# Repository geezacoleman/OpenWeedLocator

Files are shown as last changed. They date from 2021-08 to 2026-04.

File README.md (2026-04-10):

<p align="center">

</p>

# OpenWeedLocator (OWL)

**Open-source, low-cost weed detection for site-specific weed control**






OWL is a camera-based weed detection system based on the Raspberry Pi that uses green-detection algorithms to trigger relay-controlled solenoids for spot spraying. It's built entirely from off-the-shelf components and 3D-printable parts, making precision weed control accessible to anyone.

[**Website**](https://www.openweedlocator.org) | [**Documentation**](https://docs.openweedlocator.org) | [**Community**](https://community.openweedlocator.org) | [**Newsletter**](https://openagtech.beehiiv.com/)

### OWLs in Action

<table>
  <tr>
    <th>2m vehicle OWL</th>
    <th>2m robot-mounted OWL</th>
    <th>Bicycle OWL</th>
  </tr>
  <tr>
    <td align="center">
      
    </td>
    <td align="center">
      
    </td>
    <td align="center">
      
    </td>
  </tr>

  <tr>
    <th>12m X-fold OWL (in development)</th>
    <th>4m OWL sprayer</th>
    <th>16 channel vegetables OWL</th>
  </tr>
  <tr>
    <td align="center">
      
    </td>
    <td align="center">
      
    </td>
    <td align="center">
      
    </td>
  </tr>
</table>

---

## Quick Start

```bash
# Clone and install on Raspberry Pi (Bookworm or Trixie OS)
git clone https://github.com/geezacoleman/OpenWeedLocator owl
bash owl/owl_setup.sh
```
During this process you'll be asked to setup:
1. Green-on-Green - this adds about 2GB of dependencies
2. Dashboard - standlone or networked

One complete you'll need to reboot and then it should be running.

To confirm, run `sudo systemctl status owl.service` or `sudo journalctl -u owl.service -f`

See the [two step installation guide](https://docs.openweedlocator.org/en/latest/software/index.html) for detailed instructions.

## Documentation

- [**Getting Started**](https://docs.openweedlocator.org/en/latest/getting-started/index.html) - What you need, how it works
- [**Hardware Assembly**](https://docs.openweedlocator.org/en/latest/hardware/index.html) - Parts list, wiring, 3D printing
- [**Software Setup**](https://docs.openweedlocator.org/en/latest/hardware/index.html) - Installation, configuration, algorithms
- [**Controller Setup**](https://docs.openweedlocator.org/en/latest/controllers/index.html) - Standalone and networked dashboards
- [**Troubleshooting**](https://docs.openweedlocator.org/en/latest/troubleshooting/index.html) - Common issues and fixes

### Contributing

Contributions are welcome! See [CONTRIBUTING.md](CONTRIBUTING.md) for guidelines, or join the conversation at [community.openweedlocator.org](https://community.openweedlocator.org).

## Citing OWL

OpenWeedLocator was originally published in [Scientific Reports](https://www.nature.com/articles/s41598-021-03858-9). 
```
@article{Coleman2022,
author = {Coleman, Guy and Salter, William and Walsh, Michael},
doi = {10.1038/s41598-021-03858-9},
issn = {2045-2322},
journal = {Scientific Reports},
number = {1},
pages = {170},
title = {{OpenWeedLocator (OWL): an open-source, low-cost device for fallow weed detection}},
url = {https://doi.org/10.1038/s41598-021-03858-9},
volume = {12},
year = {2022}
}

```
The OWL speed testing paper has been published in [Computers and Electronics in Agriculture](https://www.sciencedirect.com/science/article/pii/S0168169923008074). Please
consider citing the published article using the details below.
```
@article{Coleman2023,
author = {Coleman, Guy R.Y. and Macintyre, Angus and Walsh, Michael J. and Salter, William T.},
doi = {10.1016/j.compag.2023.108419},
issn = {0168-1699},
journal = {Computers and Electronics in Agriculture},
pages = {108419},
title = {{Investigating image-based fallow weed detection performance on Raphanus sativus and Avena sativa at speeds up to 30 km h$^{-1}$}},
url = {https://doi.org/10.1016/j.compag.2023.108419},
volume = {215},
year = {2023}
}
```

### License

This project is licensed under the [MIT License](LICENSE).

## Star History

Star History Chart (https://star-history.com/#geezacoleman/OpenWeedLocator&Timeline)

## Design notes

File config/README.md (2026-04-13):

# Configuration Files

OWL uses INI configuration files to control both detection behaviour and system infrastructure. These are split into two types: **detection config** and **infrastructure config**.

## Detection Config (GENERAL_CONFIG.ini)

`GENERAL_CONFIG.ini` is the single unified detection configuration file. It controls algorithm choice, colour thresholds, camera settings, relay wiring, data collection, tracking, and sensitivity presets -- all in one file.

`GENERAL_CONFIG.ini` and `CONTROLLER.ini` are **protected defaults** -- the dashboard won't let you overwrite or delete them. When you change settings via the dashboard, OWL creates a timestamped copy (e.g. `config_20260207_153022.ini`) and writes changes there.

### Which config is active?

`active_config.txt` contains the path to the detection config OWL loads on boot. If this file doesn't exist, OWL defaults to `config/GENERAL_CONFIG.ini`. You can change the active config from the dashboard or by editing this file directly.

### Sensitivity presets

Rather than separate config files, sensitivity presets are embedded as sections within `GENERAL_CONFIG.ini`:

| Section | Description |
|---|---|
| `[Sensitivity_Low]` | Fewer false positives, may miss smaller weeds |
| `[Sensitivity_Medium]` | Good general-purpose starting point |
| `[Sensitivity_High]` | Catches more weeds, more likely to spray non-targets |

The `[Sensitivity]` section holds the `active` key (`low`, `medium`, or `high`) which determines which preset is applied. Presets only change the 9 `[GreenOnBrown]` threshold values -- hardware settings (relay count, resolution, GPIO pins) are never touched.

You can create custom presets by saving from the dashboard. Custom presets are saved as additional `[Sensitivity_*]` sections and can be deleted from the dashboard. The three built-in presets (Low/Medium/High) cannot be deleted.

### Key sections in GENERAL_CONFIG.ini

| Section | What it controls |
|---|---|
| `[System]` | Algorithm selection, relay count, actuation timing |
| `[Camera]` | Resolution, exposure compensation, crop factors |
| `[GreenOnBrown]` | Colour thresholds (ExG, Hue, Saturation, Brightness min/max), minimum detection area |
| `[GreenOnGreen]` | YOLO model path, confidence, class filtering, actuation mode (for in-crop weed detection) |
| `[Controller]` | Hardware controller type (`none`, `ute`, `advanced`) and pin mappings |
| `[DataCollection]` | Image sampling settings, save directory, logging |
| `[Relays]` | Maps relay IDs to GPIO pin numbers |
| `[Tracking]` | ByteTrack weed tracking settings |
| `[Visualisation]` | Display settings when running with `--show-display` |
| `[Sensitivity]` | Active sensitivity preset |
| `[Sensitivity_Low/Medium/High]` | Built-in sensitivity preset thresholds |

---

## All configurable options

Defaults shown are from `GENERAL_CONFIG.ini`.

### `[System]`

| Key | Default | Range / Valid values | Description |
|-----|---|---|---|
| `algorithm` | `exhsv` | `exg`, `exgr`, `maxg`, `nexg`, `exhsv`, `hsv`, `gndvi`, `gog`, `gog-hybrid` | Detection algorithm (see table below) |
| `input_file_or_directory` | *(empty)* | File or directory path | Path to video, image, or directory for offline processing. Leave empty for live camera |
| `relay_num` | `4` | 0+ (integer) | Number of relays connected to the OWL. Must match entries in `[Relays]` |
| `actuation_duration` | `0.15` | Seconds (float) | How long each relay stays on when a weed is detected |
| `delay` | `0` | Seconds (float) | Delay between detection and relay actuation. Use for speed/distance compensation |
| `actuation_zone` | `100` | 1--100 (integer) | Percentage of the frame width used for relay lane mapping |

### Detection algorithms

| Algorithm | Name | Formula / Method | Notes |
|---|---|---|---|
| `exg` | Excess Green | 2g - r - b | Simple and fast. Woebbecke et al. 1995 |
| `exgr` | Excess Green minus Excess Red | ExG - (1.4r - g) | Better soil rejection than ExG alone |
| `maxg` | Maximum Green | 24g - 19r - 2b | Jin et al. 2021 |
| `nexg` | Normalised Excess Green | Standardised ExG using channel ratios | Less sensitive to lighting variation |
| `exhsv` | ExG + HSV combined | Normalised ExG masked by HSV thresholds | **Default.** Best balance of accuracy and robustness |
| `hsv` | HSV thresholding | Hue/Saturation/Value range filter | Fast, but sensitive to lighting changes |
| `gndvi` | Green NDVI | (NIR - green) / (NIR + green) | **Requires NIR camera.** Not for standard setups |
| `gog` | Green-on-Green | Ultralytics YOLO object detection | For in-crop weed detection. Requires a trained model (see `[GreenOnGreen]`) |
| `gog-hybrid` | AI + Colour | YOLO crop mask + ExHSV colour detection | Uses YOLO to identify crop regions, then runs ExHSV on non-crop areas. Best of both worlds for in-crop scenarios |

All algorithms except `gog`, `gog-hybrid`, and `hsv` use the `[GreenOnBrown]` thresholds. The `hsv` algorithm uses only the HSV thresholds (hue, saturation, brightness). The `gog` algorithm ignores `[GreenOnBrown]` entirely and uses `[GreenOnGreen]` settings instead. The `gog-hybrid` algorithm uses both `[GreenOnGreen]` (for YOLO crop detection) and `[GreenOnBrown]` (for ExHSV weed detection in non-crop areas).

### `[Camera]`

| Key | Default | Range / Valid values | Description |
|-----|---|---|---|
| `resolution_width` | `1456` | 1+ (integer) | Camera capture width in pixels |
| `resolution_height` | `1088` | 1+ (integer) | Camera capture height in pixels |
| `exp_compensation` | `-2` | -10 to 10 (integer) | Exposure compensation. Negative = darker (reduces sky/soil glare) |
| `crop_factor_horizontal` | `0.02` | 0.0 to 0.5 (float) | Fraction of image width to crop from each side. Removes edge distortion |
| `crop_factor_vertical` | `0.02` | 0.0 to 0.5 (float) | Fraction of image height to crop from top and bottom |

Higher resolution gives better detection of small weeds but is slower. The dashboard provides resolution presets as a dropdown.

### `[GreenOnBrown]`

Used by all algorithms except `gog`. The ExG thresholds are used by `exg`, `exgr`, `maxg`, `nexg`, `exhsv`, and `gndvi`. The HSV thresholds are used by `hsv` and `exhsv`.

| Key | Default | Range | Description |
|-----|---|---|---|
| `exg_min` | `25` | 0--255 | Minimum Excess Green value. Pixels below this are ignored. Higher = stricter |
| `exg_max` | `200` | 0--255 | Maximum Excess Green value. Pixels above this are ignored |
| `hue_min` | `39` | 0--180 | Minimum hue (OpenCV scale). Green vegetation is roughly 35--85 |
| `hue_max` | `83` | 0--180 | Maximum hue |
| `saturation_min` | `50` | 0--255 | Minimum colour saturation. Low values include washed-out/grey pixels |
| `saturation_max` | `220` | 0--255 | Maximum colour saturation |
| `brightness_min` | `60` | 0--255 | Minimum brightness. Low values include very dark pixels (shadows) |
| `brightness_max` | `190` | 0--255 | Maximum brightness. High values include very bright pixels (glare) |
| `min_detection_area` | `10` | 0+ (integer) | Minimum contour area in pixels to count as a weed. Higher = ignore small detections |
| `invert_hue` | `False` | `True` / `False` | If True, detect pixels *outside* the hue range instead of inside. Useful for non-green targets |

**Tuning tips:** Start with the medium sensitivity preset and adjust using `--show-display` or the dashboard sliders. Wider ranges (lower mins, higher maxes) catch more weeds but increase false positives. Narrower ranges are more precise but may miss weeds in variable lighting.

### `[GreenOnGreen]`

Used when `algorithm = gog` or `algorithm = gog-hybrid`. Green-on-Green detection uses [Ultralytics YOLO](https://docs.ultralytics.com/) for object detection or instance segmentation. In `gog` mode, YOLO detects weeds directly. In `gog-hybrid` mode, YOLO identifies crop regions, which are masked out before running ExHSV colour detection on the remaining (non-crop) areas -- this combines AI crop recognition with colour-based weed detection for in-crop scenarios.

**Model format:** NCNN is the recommended format for Raspberry Pi -- it runs fastest on ARM CPUs. PyTorch (.pt) models also work but are slower. To convert a model to NCNN, use `yolo export model=your_model.pt format=ncnn`.

**Model loading:** Point `model_path` at an NCNN directory (containing `.param` and `.bin` files), a `.pt` file, or a parent directory containing models. OWL searches for NCNN models first, then falls back to `.pt` files.

| Key | Default | Range / Valid values | Description |
|-----|---|---|---|
| `model_path` | `models` | Directory or file path | Path to YOLO model. Can be an NCNN directory, `.pt` file, or parent directory containing models |
| `confidence` | `0.5` | 0.0--1.0 (float) | Minimum detection confidence. Lower = more detections (more false positives), higher = fewer but more certain |
| `detect_classes` | *(empty)* | Comma-separated class names | Filter detections to specific classes. Empty = detect all classes the model knows |
| `actuation_mode` | `centre` | `centre`, `zone` | How detections trigger relays (see below) |
| `min_detection_pixels` | `50` | 1+ (integer) | Minimum weed pixels in a relay lane to trigger actuation. Only used in `zone` mode |
| `inference_resolution` | `320` | 160--1280 (integer) | YOLO input resolution for `gog-hybrid` mode. Lower = faster inference, higher = better crop detection. Only used in hybrid mode |
| `crop_buffer_px` | `20` | 0--50 (integer) | Dilation buffer in pixels around detected crop regions in `gog-hybrid` mode. Larger buffer = more area masked as crop (fewer false positives on crop edges). Only used in hybrid mode |

**Actuation modes:**

- **`centre`** (default) -- Uses the centre point of each detection bounding box to determine which relay lane the weed falls in. Works with both detection and segmentation models. Simple and reliable.

- **`zone`** -- Uses the segmentation mask to count weed pixels in each relay lane. A relay fires only if the pixel count exceeds `min_detection_pixels`. **Requires a segmentation model** (detection-only models have no mask data). More precise for large or irregularly shaped weeds.

### `[Tracking]`

Optional weed tracking using ByteTrack. When enabled, YOLO runs in tracking mode to maintain consistent weed IDs across frames. This enables class smoothing (stabilising noisy per-frame class predictions) and crop mask stabilisation (persisting crop masks for a few frames after the crop leaves the field of view).

| Key | Default | Range / Valid values | Description |
|-----|---|---|---|
| `tracking_enabled` | `False` | `True` / `False` | Enable ByteTrack weed tracking |
| `track_class_window` | `5` | 1+ (integer) | Number of recent frames to use for majority-vote class smoothing |
| `track_crop_persist` | `3` | 0+ (integer) | Number of frames to persist a crop mask after the crop is no longer detected. Only used in `gog-hybrid` mode |

### `[Controller]`

Controls the optional hardware input controller (physical switches on the OWL unit). Most users set this to `none` and use the web dashboard instead.

| Key | Default | Range / Valid values | Description |
|-----|---|---|---|
| `controller_type` | `none` | `none`, `ute`, `advanced` | Hardware controller type. `none` = no physical switches |

**Shared LED pins** (used by both Ute and Advanced controllers):

| Key | Default | Range / Valid values | Description |
|-----|---|---|---|
| `status_led_pin` | `40` | 1--40 (BOARD pin) | Status indicator LED (boot, detection, recording states) |
| `gps_led_pin` | `38` | 1--40 (BOARD pin) | GPS status LED (solid = fix, flash = acquiring, double-flash = error) |

**Ute controller** (`controller_type = ute`) -- a single toggle switch:

| Key | Default | Range / Valid values | Description |
|-----|---|---|---|
| `switch_pin` | `36` | 1--40 (BOARD pin) | GPIO pin for the toggle switch |
| `switch_purpose` | `recording` | `recording`, `detection` | What the switch controls. `recording` toggles image saving, `detection` toggles weed detection |

**Advanced controller** (`controller_type = advanced`) -- multiple switches for full field control:

| Key | Default | Range / Valid values | Description |
|-----|---|---|---|
| `detection_mode_pin_up` | `36` | 1--40 (BOARD pin) | Switch pin for detection mode up |
| `detection_mode_pin_down` | `35` | 1--40 (BOARD pin) | Switch pin for detection mode down |
| `recording_pin` | `33` | 1--40 (BOARD pin) | Switch pin to toggle image recording |
| `sensitivity_pin` | `32` | 1--40 (BOARD pin) | Switch pin to cycle sensitivity presets (low/high toggle) |

> **Note:** All pin values use BOARD numbering (physical pin position on the header). Ute and Advanced controllers are mutually exclusive — only pins for the active controller type are used.

The hardware switch cycles between the Low and High sensitivity presets (two-position toggle). The web dashboard supports all three levels (low/medium/high) via MQTT. Both use the `SensitivityManager` which reads from the `[Sensitivity_*]` sections.

### `[Sensitivity]`

| Key | Default | Range / Valid values | Description |
|-----|---|---|---|
| `active` | `medium` | `low`, `medium`, `high`, or custom preset name | The currently active sensitivity preset |

### `[Sensitivity_Low]`, `[Sensitivity_Medium]`, `[Sensitivity_High]`

Each preset section contains the same 9 keys as `[GreenOnBrown]` (the threshold values). When a preset is applied, these values overwrite the corresponding `[GreenOnBrown]` keys at runtime. Example:

```ini
[Sensitivity_Low]
exg_min = 25
exg_max = 200
hue_min = 41
hue_max = 80
saturation_min = 52
saturation_max = 218
brightness_min = 62
brightness_max = 188
min_detection_area = 20
```

### `[Visualisation]`

| Key | Default | Range / Valid values | Description |
|-----|---|---|---|
| `image_loop_time` | `5` | Seconds (integer) | Time each image is displayed when processing a directory of images with `--show-display` |

### `[DataCollection]`

| Key | Default | Range / Valid values | Description |
|-----|---|---|---|
| `image_sample_enable` | `False` | `True` / `False` | Enable automatic image saving for dataset collection |
| `sample_method` | `whole` | `bbox`, `square`, `whole` | How images are saved. `whole` = full frame, `bbox` = cropped to detection bounding box, `square` = square crop around detection |
| `sample_frequency` | `30` | 1+ (integer) | Save an image every N frames. 30 = roughly once per second at 30fps |
| `save_directory` | `/media/owl/SanDisk` | Directory path | Where to save collected images. Typically a USB drive |
| `detection_enable` | `True` | `True` / `False` | Enable weed detection and relay actuation. Set to `False` for data-collection-only mode |
| `log_fps` | `False` | `True` / `False` | Log frames-per-second to the console |
| `camera_name` | `cam1` | Text string | Identifier for this camera in saved data. Useful for multi-camera rigs |

### `[Relays]`

Maps relay IDs to GPIO board pin numbers. The number of entries here must be at least `relay_num` from `[System]`.

| Key | Default | Range | Description |
|-----|---|---|---|
| `0` | `13` | 1--40 (board pin) | GPIO pin for relay 0 (leftmost spray zone) |
| `1` | `15` | 1--40 (board pin) | GPIO pin for relay 1 |
| `2` | `16` | 1--40 (board pin) | GPIO pin for relay 2 |
| `3` | `18` | 1--40 (board pin) | GPIO pin for relay 3 (rightmost spray zone) |

Add more entries (e.g. `4 = 22`) if you have more than 4 relays, and update `relay_num` to match.

---

## Infrastructure Config (CONTROLLER.ini)

`CONTROLLER.ini` controls how OWL connects to dashboards, networks, and GPS. It is **not included in the repository** -- it gets created automatically when you run the setup script (`owl_setup.sh`).

If `CONTROLLER.ini` does not exist, OWL runs in basic detection-only mode with no MQTT, no web dashboard, and no remote control. This is the default for a fresh install.

See `CONTROLLER_TEMPLATE.ini` for a fully documented reference with explanations of every setting. To create one manually:

```bash
cp config/CONTROLLER_TEMPLATE.ini config/CONTROLLER.ini
# Then edit CONTROLLER.ini with your settings
```

### Key sections in CONTROLLER.ini

| Section | What it controls |
|---|---|
| `[MQTT]` | Enable/disable MQTT, broker address, device ID |
| `[Network]` | Operation mode (`standalone` or `networked`), IP addresses |
| `[WebDashboard]` | Flask dashboard port |
| `[GPS]` | GPS source, serial settings, networked GPS server config |
| `[Actuation]` | Speed-adaptive actuation settings |

## How the two files work together

OWL reads both files on startup. `GENERAL_CONFIG.ini` is read first, then `CONTROLLER.ini` is layered on top. If the same key exists in both files, `CONTROLLER.ini` wins (this is how Python's ConfigParser merge works). This means old custom configs that still have `[MQTT]` or `[Network]` sections will still work -- `CONTROLLER.ini` values take precedence.

## Operation Modes

OWL supports three ways of running, depending on your setup:

### No controller (default)

Out of the box, with no setup script run and no `CONTROLLER.ini`, OWL just does detection. No dashboard, no MQTT, no remote control. It reads images from the camera, runs the detection algorithm, and triggers relays. This is the simplest setup -- just wire it up, power it on, and it works.

**When to use:** Single OWL unit where you just need it to spray weeds. No touchscreen, no remote monitoring needed. Configure detection thresholds using `--show-display` on a monitor, save to a preset file, and let it run.

### Standalone mode

A single OWL with its own WiFi hotspot and web dashboard. The OWL creates a WiFi network you can connect to from a phone, tablet, or in-cab touchscreen. The dashboard lets you start/stop detection, adjust thresholds with live camera preview, save presets, and monitor system health -- all from a browser.

Everything runs on one Pi: the detection loop, the MQTT broker, the web server, and the dashboard.

**When to use:** Single OWL unit where you want a touchscreen or remote control. Typical setup: OWL Pi with a 7" touchscreen mounted in the cab, connected to the OWL's own hotspot.

**Setup:** Run `owl_setup.sh`, select "yes" to dashboard, then select "Standalone" mode. The setup script creates the hotspot, installs the MQTT broker, configures Nginx, and writes `CONTROLLER.ini` with `mode = standalone`.

### Networked mode

Multiple OWLs connected to a shared WiFi network, all reporting to a central controller. The central controller runs on a separate Pi (typically in the cab with a touchscreen) and shows all connected OWLs in one dashboard. You can monitor, control, and configure every OWL from a single screen.

Each OWL connects to the network as a client with a static IP and publishes its state to the central MQTT broker. The central controller discovers OWLs automatically -- no manual registration needed.

**When to use:** Multi-boom or multi-unit setups. For example, a 36m spray rig with 3 OWLs each covering 12m, all visible and controllable from one in-cab display.

**Setup requires two scripts:**

1. **On the central controller Pi:** Run `controller/networked/in-cab_controller_setup.sh`. This installs the MQTT broker, the networked dashboard, configures WiFi, and optionally sets up kiosk mode for a touchscreen.

2. **On each OWL Pi:** Run `owl_setup.sh`, select "yes" to dashboard, then select "Networked" mode. Enter the central controller's IP when prompted. The setup script configures WiFi as a client, writes `CONTROLLER.ini` with `mode = networked` and the broker IP pointing to the controller.

## GPS Setup

OWL supports GPS tracking via a Teltonika RUTX14 (or similar) industrial router that pushes NMEA sentences over TCP. GPS data is used for:

- Live speed, heading, and satellite display on the GPS tab
- Session statistics: distance travelled, time active, area covered (hectares)
- GeoJSON track recording saved to disk for each detection session

### How it works

The **central controller** (networked mode) runs a TCP server that listens for NMEA connections. The Teltonika router connects to this server and pushes standard NMEA sentences (`$GPRMC`, `$GPGGA`, `$GPVTG`, `$GPGSV`). The GPS Manager parses these, updates the live GPS state, and feeds the session tracker and track recorder.

```
Teltonika RUTX14          Central Controller (Pi)           Browser
    GPS antenna               GPSManager                    GPS Tab
        |                         |                            |
        +--- NMEA over TCP ------>| port 8500                  |
                                  |  parse NMEA                |
                                  |  update GPSState           |
                                  |  update SessionStats       |
                                  |  write GeoJSON track       |
                                  |                            |
                                  +--- /api/gps (JSON) ------->|
                                                               | speed, heading
                                                               | satellites, area
```

Sessions auto-start when any OWL begins detection and auto-stop when all OWLs stop.

### Step 1: Configure CONTROLLER.ini on the central controller

Edit `config/CONTROLLER.ini` on the Pi running the networked controller:

```ini
[GPS]
# Enable the GPS TCP server
enable = True

# TCP port to listen on (must match Teltonika config)
nmea_port = 8500

# Spray boom width in metres (for area calculation)
boom_width = 12.0

# Directory for GeoJSON track files
track_save_directory = tracks
```

The `source`, `port`, and `baudrate` keys are only used by owl.py for serial GPS modules -- they are ignored by the networked controller.

### Step 2: Configure the Teltonika RUTX14

On the Teltonika router's web interface (typically `192.168.1.1`):

1. **Services > GPS > General**: Enable GPS
2. **Services > GPS > NMEA Forwarding**:
   - Enable NMEA forwarding
   - Protocol: **TCP**
   - Hostname/IP: the central controller's IP address (e.g. `192.168.1.2`)
   - Port: **8500** (must match `nmea_port` in CONTROLLER.ini)
   - NMEA sentences: enable at minimum **GGA** and **RMC**. Also enable **VTG** (speed) and **GSV** (satellites) for full data.

### Step 3: Firewall

The setup script (`controller/shared/setup.sh`) automatically opens port 8500 in UFW:

```bash
sudo ufw allow 8500/tcp
```

If you didn't use the setup script, add this rule manually.

### Step 4: Verify

1. Restart the networked controller: `sudo systemctl restart owl-controller.service` (or run `python controller/networked/networked.py` manually)
2. Check the logs for: `GPS Manager started on port 8500` and `GPS client connected from ...`
3. Open the GPS tab in the browser -- it should show satellite count, speed, and heading once the Teltonika gets a GPS fix

### Troubleshooting

| Symptom | Cause | Fix |
|---|---|-----|
| GPS tab shows "DISCONNECTED" | GPSManager not started | Check `enable = True` in `[GPS]` section of CONTROLLER.ini |
| GPSManager started but no client connects | Teltonika can't reach the controller | Verify network connectivity: `ping <controller-ip>` from Teltonika. Check UFW: `sudo ufw status` should show 8500/tcp ALLOW |
| Client connects but no fix data | Teltonika GPS has no satellite lock | Check the Teltonika GPS status page. Move to a location with sky visibility. First fix can take several minutes |
| Speed shows 0 but position is valid | VTG sentence not enabled on Teltonika | Enable VTG in Teltonika NMEA forwarding settings |
| Track files are empty | Session never started | Detection must be enabled on at least one OWL. Sessions auto-start/stop with detection |

### GPS config reference

| Key | Used by | Default | Description |
|-----|---|---|---|
| `source` | owl.py | `none` | GPS source for individual OWL (`none`/`serial`/`tcp`) |
| `port` | owl.py | `/dev/ttyUSB0` | Serial port (when `source = serial`) |
| `baudrate` | owl.py | `9600` | Serial baud rate (when `source = serial`) |
| `enable` | networked controller | `False` | Start GPS TCP server on the central controller |
| `nmea_port` | networked controller | `8500` | TCP port for NMEA connections |
| `boom_width` | networked controller | `12.0` | Boom width in metres for area calculation |
| `track_save_directory` | networked controller | `tracks` | Directory for GeoJSON track files |

## Custom presets saved from the dashboard

When you save a new preset from the dashboard (standalone or networked), it creates a timestamped INI file in this directory (e.g. `config_20260207_153022.ini`) and saves the preset as a new `[Sensitivity_*]` section. You can set any saved preset as the active boot config from the dashboard.

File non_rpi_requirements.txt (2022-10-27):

## IMPORTANT - for NON Raspberry Pi use. Only use this file if you are setting up an environment on a non Rasperry Pi device. ##

glob2==0.7
imutils==0.5.4
numpy==1.23.4
opencv-python==4.6.0.66
pandas==1.5.1

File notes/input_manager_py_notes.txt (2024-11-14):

################################################################################
Notes on input_manager.py

Summary completed on 14/11/2024
Summary based on commit 95dfb6b
################################################################################

Purpose:
- Manages physical control interfaces for OWL
- Handles GPIO button inputs
- Controls detection and recording states
- Provides platform compatibility checks

Functions:
- is_raspberry_pi
- get_rpi_version

Classes:
- UteController
- AdvancedController

UteController class:
- Single-switch control interface
- Methods:
  - __init__
  - update_state
  - toggle_state
  - weed_detect_indicator
  - image_write_indicator
  - run
  - stop

UteController class --> __init__ method:
- Takes detection_state, sample_state, stop_flag
- Takes owl_instance, status_indicator
- Takes switch_purpose (recording/detection)
- Takes switch_board_pin, bounce_time
- Initializes GPIO button handlers

UteController class --> update_state method:
- Checks switch position
- Updates detection or recording state
- Toggles LED indicators
- Controls weed detection/image sampling

AdvancedController class:
- Multi-switch interface for advanced control
- Methods:
  - __init__
  - update_state
  - update_recording_state
  - update_sensitivity_state
  - update_sensitivity_settings
  - set_detection_mode
  - update_detection_mode_state
  - weed_detect_indicator
  - image_write_indicator
  - run
  - stop
  - _read_config

AdvancedController class --> __init__ method:
- Takes recording/sensitivity/detection states
- Takes owl_instance, status_indicator
- Takes config paths for sensitivity settings
- Takes button pin mappings and bounce time
- Initializes multiple GPIO buttons
- Sets up button event handlers

AdvancedController class --> update_state method:
- Updates all control states:
  * Recording state
  * Sensitivity state
  * Detection mode state

AdvancedController class --> set_detection_mode method:
- Takes mode parameter (0=detect, 1=off, 2=all on)
- Controls relay states
- Updates status indicators

Platform Handling:
- Detects Raspberry Pi platform
- Provides GPIO access on Pi
- Testing mode on non-Pi platforms
- Version detection for Pi models

Dependencies:
- gpiozero: GPIO control (Pi only)
- configparser: Config file reading
- cv2: GUI trackbar updates
- threading: Process control
- logging: Status messages

GPIO Configuration:
- Button setup with bounce time
- Event handler registration
- State management
- LED indicator control

Thread Safety:
- State locking for shared variables
- Safe process termination
- Event-based status updates

Error Handling:
- Platform compatibility checks
- GPIO initialization errors
- Config file reading errors
- Process management safety

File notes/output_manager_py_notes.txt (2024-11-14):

################################################################################
Notes on output_manager.py

Summary completed on 14/11/2024
Summary based on commit 95dfb6b
################################################################################

Purpose:
- Controls hardware outputs for OWL system
- Manages relay board control and status indicators
- Provides test interfaces for non-Pi development

Classes:
- TestRelay
- TestBuzzer
- TestLED
- BaseStatusIndicator
- HeadlessStatusIndicator
- UteStatusIndicator
- AdvancedStatusIndicator
- RelayControl
- RelayController

Entrypoint:
- Has __main__ check for testing status indicators
- Sets testing flag via get_platform_config() if not on Raspberry Pi
- Uses terminal messages instead of GPIO when in test mode

TestRelay class:
- Simulates relay hardware for testing
- Methods:
  - __init__
  - on
  - off

TestRelay class --> __init__ method:
- Takes relay_number and verbose flag
- Stores them as instance attributes

TestRelay class --> on method:
- Prints "[TEST] Relay {number} ON" if verbose enabled

TestRelay class --> off method:
- Prints "[TEST] Relay {number} OFF" if verbose enabled

TestBuzzer class:
- Simulates buzzer hardware for testing
- Methods:
  - beep

TestBuzzer class --> beep method:
- Takes on_time, off_time, n repeats, verbose flag
- Prints "BEEP" n times if verbose enabled

TestLED class:
- Simulates LED hardware for testing
- Methods:
  - __init__
  - blink
  - on
  - off

TestLED class --> __init__ method:
- Takes pin number
- Stores as instance attribute

TestLED class --> blink method:
- Takes on_time, off_time, n repeats, verbose flag
- Prints "BLINK {pin}" n times if verbose enabled

TestLED class --> on/off methods:
- Print "LED {pin} ON/OFF" respectively

BaseStatusIndicator class:
- Base class for all status indicators
- Handles storage monitoring and LED control
- Methods:
  - __init__
  - start_storage_indicator
  - run_update
  - update
  - error
  - stop

BaseStatusIndicator class --> __init__ method:
- Takes save_directory and no_save flag
- Initializes storage monitoring
- Sets up LED control threads
- Configures system LEDs

BaseStatusIndicator class --> update method:
- Monitors storage usage
- Updates LED states based on storage
- Triggers errors if storage full

HeadlessStatusIndicator class:
- Minimal implementation without physical indicators
- Inherits from BaseStatusIndicator
- Only monitors storage capacity
- Methods:
  - __init__
  - _update_storage_indicator

UteStatusIndicator class:
- Two-LED indicator system
- Inherits from BaseStatusIndicator
- Methods:
  - __init__
  - _update_storage_indicator
  - setup_success
  - image_write_indicator
  - error
  - stop

UteStatusIndicator class --> __init__ method:
- Takes save_directory and LED pin numbers
- Initializes record and storage LEDs
- Sets up status monitoring

UteStatusIndicator class --> _update_storage_indicator method:
- Takes percent_full value
- Changes LED blink patterns based on storage level:
  * >90%: Solid storage LED
  * >85%: Fast blink
  * >80%: Medium blink
  * >75%: Slow blink
  * >50%: Very slow blink
  * <50%: Extremely slow blink

RelayControl class:
- Direct hardware interface for relay board
- Methods:
  - __init__
  - relay_on
  - relay_off
  - beep
  - all_on
  - all_off
  - remove
  - clear
  - stop

RelayControl class --> __init__ method:
- Takes relay_dict mapping relays to GPIO pins
- Initializes buzzer on BOARD7
- Creates OutputDevice for each relay
- Sets up test devices if not on Pi

RelayController class:
- Manages relay timing and job queues
- Methods:
  - __init__
  - receive
  - consumer

RelayController class --> __init__ method:
- Takes relay_dict and visualization flags
- Creates job queues for each relay
- Initializes threading conditions
- Starts consumer threads

RelayController class --> receive method:
- Takes relay, timestamp, location, delay, duration
- Queues spray job for specified relay
- Notifies consumer thread

RelayController class --> consumer method:
- Runs in separate thread for each relay
- Processes queued spray jobs
- Manages timing and relay states
- Coordinates with visualization system

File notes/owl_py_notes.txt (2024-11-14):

################################################################################
Notes on owl.py

Summary completed on 10/11/2024
Summary based on commit: 95dfb6b
################################################################################

Purpose:
- Primary control script for OWL system
- Handles real-time weed detection and sprayer control
- Manages configuration, data collection, and hardware interfaces

Entrypoint:
- Validates Python environment and imports
- Parses command line arguments:
  - --show-display: Enable visualization windows
  - --focus: Add blur detection to output
  - --input: Path to input media (image/video/directory)
- Creates Owl instance with parsed arguments
- Starts detection loop via owl.hoot()

Owl class:
Main methods:
- __init__: System initialization
- hoot: Main detection loop
- stop: Graceful shutdown
- save_parameters: Save current settings
- _log_system_info: Record system details

Initialization (__init__):
1. Configuration
   - Validates config file
   - Sets up logging
   - Initializes detection parameters
   - Creates visualization GUI if enabled

2. Hardware Setup
   - Configures camera (resolution/exposure)
   - Maps GPIO pins to relays
   - Sets up controller (None/Ute/Advanced)
   - Initializes USB storage for data collection

3. Detection Setup
   - Configures spray zones and trigger lines
   - Sets initial algorithm parameters
   - Validates hardware capabilities

Main Loop (hoot):
1. Frame Processing:
   - Acquires frame from camera/file
   - Updates detection parameters
   - Runs weed detection algorithm

2. Detection Response:
   - Maps detected weeds to spray zones
   - Triggers appropriate relays
   - Updates visualization

3. Data Collection:
   - Records frames/regions based on config
   - Manages storage limits
   - Logs performance metrics

4. User Interface:
   - Processes keyboard input
   - Updates display windows
   - Handles recording controls

Error Handling:
- Validates Python environment
- Checks hardware compatibility
- Manages GPIO conflicts
- Handles storage issues
- Reports algorithm errors

Dependencies:
Core:
- OpenCV-Python: Image processing
- NumPy: Array operations
- imutils: Image utilities

Custom modules:
- error_manager: Error handling
- input_manager: Hardware control
- config_manager: Configuration
- video_manager: Camera interface
- image_sampler: Data collection
- algorithms: Detection methods

Configuration:
- Uses .ini format
- Validated sections:
  - System: Core parameters
  - Camera: Image acquisition
  - Controller: Hardware interface
  - DataCollection: Storage settings
  - GreenOnBrown: Detection parameters
  - Relays: GPIO mappings

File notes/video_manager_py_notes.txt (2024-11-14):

################################################################################
Notes on video_manager.py

Summary completed on 14/11/2024
Summary based on commit 95dfb6b
################################################################################

Purpose:
- Manages different camera types for video capture
- Supports Picamera (legacy), Picamera2, and standard webcams
- Provides thread-safe video streaming

Classes:
- WebcamStream
- PiCamera2Stream
- PiCameraStream
- VideoStream

WebcamStream class:
- Handles USB/standard webcams via OpenCV
- Methods:
  - __init__
  - start
  - update
  - read
  - stop

WebcamStream class --> __init__ method:
- Takes camera source number
- Initializes VideoCapture stream
- Sets frame dimensions
- Creates thread for frame updates

WebcamStream class --> update method:
- Runs in separate thread
- Continuously reads frames
- Updates frame buffer
- Handles stream closure

PiCamera2Stream class:
- Handles newer Raspberry Pi cameras
- Methods:
  - __init__
  - start
  - update
  - read
  - stop

PiCamera2Stream class --> __init__ method:
- Takes resolution, exposure compensation
- Configures camera parameters
- Sets up thread synchronization
- Detects camera model (imx296/imx477/imx708)

PiCamera2Stream class --> update method:
- Thread-safe frame capture
- Uses condition/lock for synchronization
- Handles camera cleanup

PiCameraStream class:
- Handles legacy Raspberry Pi camera
- Methods:
  - __init__
  - start
  - update
  - read
  - stop

PiCameraStream class --> __init__ method:
- Takes resolution, exposure compensation
- Sets PiCamera parameters
- Initializes frame buffer
- Creates capture stream

PiCameraStream class --> update method:
- Continuous frame capture
- Updates frame buffer
- Handles resource cleanup

VideoStream class:
- Factory class to create appropriate stream
- Methods:
  - __init__
  - start
  - update
  - read
  - stop

VideoStream class --> __init__ method:
- Detects available camera version
- Creates appropriate stream object
- Sets frame dimensions
- Handles initialization errors

Dependencies:
- cv2: OpenCV camera interface
- picamera/picamera2: Raspberry Pi cameras
- threading: Thread management
- logging: Status and error logging

Thread Safety:
- Lock for frame buffer access
- Condition for frame synchronization
- Event for thread control
- Daemon threads for cleanup

Error Handling:
- Camera initialization failures
- Stream read errors
- Resource cleanup on errors
- Camera version compatibility

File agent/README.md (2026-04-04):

# OWL Agent Runtime

Optional AI chat assistant for the OWL dashboard. Allows users to adjust
detection settings, create custom algorithms, manage widgets, and more through
natural language conversation.

## Structure

```
agent/
  __init__.py        # Package re-exports
  engine.py          # Agentic loop: prompt assembly, LLM streaming, tool execution
  llm_provider.py    # HTTP adapter for Anthropic and OpenAI APIs (requires httpx)
  tool_registry.py   # Decorator-based tool system with tier permissions
  widget_manager.py  # Dashboard widget discovery, validation, and rendering
  sessions/          # Chat session history (git-ignored)
  widgets/           # User-installed dashboard widgets (git-ignored)
```

## Dependencies

The agent requires `httpx` for LLM API calls. This is an **optional** dependency
not included in the base `requirements.txt`.

Install manually:
```bash
pip install httpx
```

Or select "Install AI agent support" during in-cab controller setup.

## Usage

Both controllers import the agent with a `try/except` guard. If `httpx` is not
installed, the agent tab is simply disabled -- the rest of the dashboard works
normally.

```python
from agent import AgentEngine, ToolRegistry, WidgetManager
```

## How it works

1. The **ToolRegistry** discovers `@owl_tool` decorated functions and exposes
   them as JSON schemas to the LLM.
2. The **AgentEngine** assembles a system prompt with current OWL state, streams
   the user's message to an LLM provider, executes any tool calls, and loops
   until the model returns a text response.
3. Tools are organised into tiers: `observe` (read-only), `apply` (change
   settings), and `developer` (file editing, git operations).

## Related

- `custom_algorithms/` (repo root) -- user-created detection algorithms. Shared
  with the core detection pipeline (`greenonbrown.py`), so it lives outside this
  package.
- `controller/shared/js/agent.js` -- frontend chat UI
- `controller/shared/css/_agent.css` -- frontend chat styles

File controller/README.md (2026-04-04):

# Web Controllers

OWL has two web-based dashboards for monitoring and controlling detection in the field. Which one you use depends on whether you have a single OWL or multiple OWLs on one rig.

## Do I need a controller?

No. OWL works perfectly fine without any web controller. By default (fresh install, no setup script run), OWL just runs detection -- camera in, relays out. If all you need is a box that detects weeds and triggers solenoids, you don't need any of this.

The web controllers are for when you want to:
- Start/stop detection from a touchscreen or phone
- Adjust detection thresholds with a live camera preview
- Monitor system health (CPU, memory, temperature)
- Save and load detection presets
- See GPS data and track coverage
- Control multiple OWLs from one screen

## The two controllers

### Standalone (`controller/standalone/`)

For a **single OWL unit** with its own WiFi hotspot.

The OWL Pi creates a WiFi network (e.g. "OWL-1") and runs everything locally -- detection, MQTT broker, web server, and dashboard. Connect to the hotspot from any device and open the dashboard in a browser. Typical setup is a 7" touchscreen mounted in the cab.

**What you get:**
- Live video feed with detection overlay
- Start/stop detection and image recording
- Sensitivity presets (low/medium/high)
- Threshold adjustment with sliders
- System health monitoring (CPU, temp, disk, memory)
- Config file management (save, load, delete presets)

**How to set up:**
```bash
# Run the main setup script
bash owl_setup.sh

# When prompted "Do you want to add a web dashboard?" -> yes
# When prompted for mode -> select "Standalone"
```

This installs the MQTT broker, configures the WiFi hotspot, sets up Nginx with SSL, creates the systemd service, and writes `CONTROLLER.ini` with `mode = standalone`.

**Access:** `https://owl-1.local/` or `https://10.42.0.1/` (after connecting to the OWL's hotspot)

### Networked (`controller/networked/`)

For **multiple OWL units** on a shared WiFi network, managed from one central screen.

A separate Pi acts as the central controller -- it runs the MQTT broker and the networked dashboard. Each OWL connects to the same WiFi network and publishes its status over MQTT. The controller discovers OWLs automatically and shows them all in one interface.

**What you get:**
- All connected OWLs visible in one dashboard
- Per-OWL status cards (online/offline, detection state, system health)
- Per-OWL controls (start/stop detection, restart service)
- Live video preview from any selected OWL
- Config editor with range sliders and live preview
- Push configs to individual OWLs or broadcast to all
- Config library (save, load, delete presets on the controller)
- GPS tracking with session stats, distance, area covered

**How to set up -- two steps:**

**Step 1: Set up the central controller Pi**
```bash
# On the controller Pi (the one with the touchscreen in the cab)
sudo bash controller/networked/in-cab_controller_setup.sh
```
This installs the MQTT broker, the networked dashboard, configures WiFi with a static IP, sets up Nginx, and optionally enables kiosk mode for the touchscreen.

**Step 2: Set up each OWL Pi**
```bash
# On each OWL Pi
bash owl_setup.sh

# When prompted "Do you want to add a web dashboard?" -> yes
# When prompted for mode -> select "Networked"
# Enter the central controller's IP when prompted
```
This configures WiFi as a client with a static IP, writes `CONTROLLER.ini` with `mode = networked` and the broker IP pointing to the controller.

**Access:** `https://owl-controller.local/` or `https://<controller-ip>/` (from any device on the same network)

## How MQTT connects everything

All communication between `owl.py` (the detection loop) and the dashboards happens over MQTT -- a lightweight messaging protocol designed for IoT devices.

### Standalone mode

Everything is on one Pi. The MQTT broker, owl.py, and the dashboard all talk over `localhost`. Topics are flat:

```
owl/state       -- OWL publishes its status here (heartbeat every 2s)
owl/commands    -- Dashboard sends control commands here
owl/config      -- Config data responses
```

### Networked mode

The MQTT broker runs on the central controller. Each OWL connects to it remotely and uses device-specific topics so the controller can tell them apart:

```
owl/owl-1/state       -- OWL 1's status
owl/owl-2/state       -- OWL 2's status
owl/owl-1/commands    -- Commands for OWL 1
owl/owl-2/commands    -- Commands for OWL 2
```

The controller subscribes to `owl/+/state` (wildcard) to discover all OWLs automatically. When an OWL stops sending heartbeats for 5 seconds, the controller marks it as offline.

## Directory structure

```
controller/
    standalone/             -- Single-unit dashboard
        standalone.py           Flask app
        templates/              HTML templates
        static/                 CSS and JS (per-controller)

    networked/              -- Multi-unit central controller
        networked.py            Flask app
        in-cab_controller_setup.sh  Setup script for the controller Pi
        templates/              HTML templates
        static/                 CSS and JS (per-controller)

    shared/                 -- Assets used by both controllers
        setup.sh                Setup script for OWL Pi dashboards
        css/                    Shared CSS modules (variables, buttons, etc.)
        js/                     Shared JS modules (API client, utilities, toast)
        images/                 Logos
```

Both controllers import shared CSS and JS from `controller/shared/` for consistent styling and behaviour. Controller-specific assets (layout, tabs, config editor) live in each controller's own `static/` directory.

## Troubleshooting

**Dashboard shows "MQTT Connected" but no OWLs appear (networked mode)**

The OWL is likely publishing to standalone topics (`owl/state`) instead of networked topics (`owl/{device_id}/state`). Check that `CONTROLLER.ini` on the OWL Pi has `mode = networked` under `[Network]`. If it says `standalone`, the OWL's MQTT messages won't match what the networked controller is listening for.

**Can't access the dashboard**

- Check the service is running: `systemctl status owl-dash` (standalone) or `systemctl status owl-controller` (networked)
- Check Nginx: `systemctl status nginx`
- Check MQTT: `systemctl status mosquitto`
- Test MQTT manually: `mosquitto_sub -h localhost -t "owl/#"` (you should see heartbeat messages)

**OWL shows as offline on the controller**

OWLs are marked offline after 5 seconds without a heartbeat. Check:
- Is owl.py running on the OWL? `systemctl status owl.service`
- Can the OWL reach the controller? `ping <controller-ip>` from the OWL
- Is MQTT working? `mosquitto_pub -h <controller-ip> -t "test" -m "hello"` from the OWL

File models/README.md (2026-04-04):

# Green-on-Green Weed Detection with YOLO

The OWL supports AI-based weed detection using Ultralytics YOLO models. This enables in-crop (green-on-green) weed recognition, where colour-based detection alone cannot distinguish weeds from crop.

## Supported Model Formats

| Format | Extension | Speed on Pi | Recommended |
|---|---|---|---|
| NCNN | directory with `.param` + `.bin` | Fastest | Yes |
| PyTorch | `.pt` | Slower | For testing only |

**NCNN is the recommended format for Raspberry Pi deployment.** It provides the fastest CPU inference on ARM processors (~68ms for YOLO11n on Pi 5).

## Model Directory Structure

Place your model files in this `models/` directory:

```
models/
├── yolo11n_ncnn_model/    # NCNN format (recommended for Pi)
│   ├── model.ncnn.param
│   ├── model.ncnn.bin
│   └── metadata.yaml
├── yolo11n.pt             # PyTorch format (slower, for testing)
├── labels.txt             # Legacy file (YOLO uses metadata.yaml instead)
└── README.md              # This file
```

The OWL will auto-detect models in this directory:
1. NCNN subdirectories (highest priority)
2. `.pt` files (fallback)

You can also specify an exact path in config: `model_path = models/my_model_ncnn_model`

## Model Types

YOLO supports two task types, both work with the OWL:

- **Detection models** (`yolo11n.pt`) — output bounding boxes only. Use with `actuation_mode = centre`.
- **Segmentation models** (`yolo11n-seg.pt`) — output bounding boxes + pixel masks. Use with `actuation_mode = centre` or `actuation_mode = zone`.

Both model types also work with `gog-hybrid` mode. Segmentation models provide precise crop boundaries; detection models use filled bounding boxes as crop exclusion zones (coarser but functional). The buffer dilation smooths the edges either way.

The task type is auto-detected from the model's `metadata.yaml`.

## Exporting to NCNN

Export a PyTorch model to NCNN format using the Ultralytics CLI:

```bash
# Install ultralytics with export support
pip install ultralytics[export]

# Export detection model
yolo export model=yolo11n.pt format=ncnn

# Export segmentation model
yolo export model=yolo11n-seg.pt format=ncnn
```

This creates a directory (e.g., `yolo11n_ncnn_model/`) containing the NCNN files. Copy this directory to `models/` on your Pi.

## Training Custom Models

To train a weed detection model on your own data:

1. **Collect and label images** using [Roboflow](https://roboflow.com/) or [Label Studio](https://labelstud.io/)
2. **Train with Ultralytics:**
   ```bash
   yolo detect train data=your_dataset.yaml model=yolo11n.pt epochs=100
   ```
3. **Export to NCNN** (see above)
4. **Deploy:** Copy the NCNN model directory to `models/` on the Pi

For weed detection datasets, see [Weed-AI](https://weed-ai.sydney.edu.au/).

## Configuration

Set these parameters in your config INI file under `[GreenOnGreen]`:

```ini
[GreenOnGreen]
model_path = models                  # Path to model or directory
confidence = 0.5                     # Detection threshold (0.0-1.0)
detect_classes =                     # Comma-separated class names (empty = all)
actuation_mode = centre              # 'centre' or 'zone'
min_detection_pixels = 50            # Min pixels per lane for zone mode
inference_resolution = 320           # YOLO input resolution for hybrid mode (160-1280)
crop_buffer_px = 20                  # Buffer around crop regions in hybrid mode (0-50)
```

Then set `algorithm = gog` (pure AI detection) or `algorithm = gog-hybrid` (AI crop mask + colour weed detection) in the `[System]` section.

## Actuation Modes

- **`centre`** (default) — The centre X coordinate of each detection box determines which relay fires. Works with both detection and segmentation models.
- **`zone`** (segmentation models only) — The frame is divided into lanes (one per relay). If the number of weed pixels in a lane exceeds `min_detection_pixels`, that relay fires. A large weed spanning multiple lanes triggers multiple relays simultaneously.

## Tracking (ByteTrack)

When tracking is enabled (`[Tracking] tracking_enabled = True`), YOLO runs in tracking mode using ByteTrack to maintain consistent weed IDs across frames. This enables:

- **Class smoothing** — noisy per-frame class predictions are stabilised using a majority-vote window (`track_class_window` frames). Reduces flickering between classes.
- **Crop mask stabilisation** — in `gog-hybrid` mode, crop masks persist for `track_crop_persist` frames after the crop leaves the field of view, preventing false spray triggers at crop boundaries.

Tracking config lives in the `[Tracking]` section of `GENERAL_CONFIG.ini`:

```ini
[Tracking]
tracking_enabled = False    # Enable ByteTrack weed tracking
track_class_window = 5      # Frames for majority-vote class smoothing
track_crop_persist = 3      # Frames to persist crop mask (hybrid mode only)
```

## Model Deployment via Dashboard

In networked mode, models can be uploaded to the central controller via the `/models` page and deployed to OWL units over WiFi. NCNN models should be uploaded as `.zip` files (containing `.param` and `.bin` files). The controller stores uploads in `uploads/` and OWLs download deployed models to their local `models/` directory.

## References

- [Ultralytics YOLO Documentation](https://docs.ultralytics.com/)
- [NCNN Export Guide](https://docs.ultralytics.com/integrations/ncnn/)
- [Weed-AI Dataset Repository](https://weed-ai.sydney.edu.au/)

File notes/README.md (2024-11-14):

# OWL Documentation Notes

This directory contains detailed documentation for each component of the OpenWeedLocator (OWL) system.

| File | Description | Last Updated |
|---|---|---|
| [owl.py](owl_py_notes.txt) | Main control script and system initialization | 10/11/2024 |
| [error_manager.py](error_manager_py_notes.txt) | Error handling and management system | 10/11/2024 |
| [video_manager.py](video_manager_py_notes.txt) | Camera handling and video stream management | 10/11/2024 |
| [input_manager.py](input_manager_py_notes.txt) | Physical controls and GPIO management | 10/11/2024 |
| [output_manager.py](output_manager_py_notes.txt) | Relay control and status indicators | 10/11/2024 |

Each note file follows a consistent format:
```
################################################################################
Notes on <filename>

Summary completed on DD/MM/YYYY
Summary based on commit XXXXXXX
################################################################################

Purpose:
- Core functionality overview

Classes:
- List of classes

[Detailed class documentation]
- Methods
- Attributes 
- Dependencies
```

These notes are maintained alongside code changes and are updated with each 
commit that modifies the corresponding file's functionality.

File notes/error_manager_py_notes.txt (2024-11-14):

################################################################################
Notes on error_manager.py

Summary completed on 14/11/2024
Summary based on commit 95dfb6b
################################################################################

Purpose:
- Handles all error management for OWL system
- Provides colored terminal output for errors
- Structures error hierarchy for consistent handling

Class Hierarchy:
- OWLError (Base Exception)
  |- StorageError
     |- USBError
        |- USBMountError
        |- USBWriteError
        |- NoWritableUSBError
     |- StorageSystemError
  |- OWLProcessError
     |- OWLAlreadyRunningError
  |- OWLControllerError
     |- ControllerPinError
     |- ControllerConfigError
  |- OWLConfigError
     |- ConfigFileError
     |- ConfigSectionError
     |- ConfigKeyError
     |- ConfigValueError
  |- AlgorithmError
  |- OpenCVError
  |- DependencyError

OWLError class:
- Base exception for all OWL errors
- Methods:
  - __init__
  - colorize
  - format_error_header
  - format_section

OWLError class --> __init__ method:
- Takes message and details dictionary
- Sets timestamp and error ID
- Initializes base Exception

OWLError class --> colorize method:
- Takes text, color, bold flag, underline flag
- Returns ANSI-colored string for terminal output

StorageError classes:
- USBMountError: USB device mounting failures
- USBWriteError: USB write permission issues
- NoWritableUSBError: No available USB storage
- StorageSystemError: Platform compatibility issues

OWLProcessError classes:
- OWLAlreadyRunningError: Handles duplicate instances
- Methods:
  - get_owl_processes: Lists running OWL instances

OWLControllerError classes:
- ControllerPinError: GPIO pin configuration issues
- ControllerConfigError: Controller setup problems

OWLConfigError classes:
- ConfigFileError: Missing/invalid config file
- ConfigSectionError: Missing required sections
- ConfigKeyError: Missing required keys
- ConfigValueError: Invalid configuration values

AlgorithmError class:
- Handles detection algorithm failures
- Methods:
  - handle: Logs error and stops OWL
- Predefined messages for:
  - ModuleNotFoundError
  - IndexError/FileNotFoundError
  - ValueError

OpenCVError class:
- OpenCV import/initialization failures
- Methods:
  - handle: Logs error and exits

DependencyError class:
- Python package dependency issues
- Methods:
  - _format_pip_package_error
  - _format_local_file_error
  - handle

Error Display Features:
- Colored terminal output
- Standardized error headers
- Formatted error sections
- Timestamped error IDs
- Detailed error messages

Dependencies:
- subprocess: Process management
- logging: Error logging
- pathlib: Path handling
- datetime: Timestamp generation

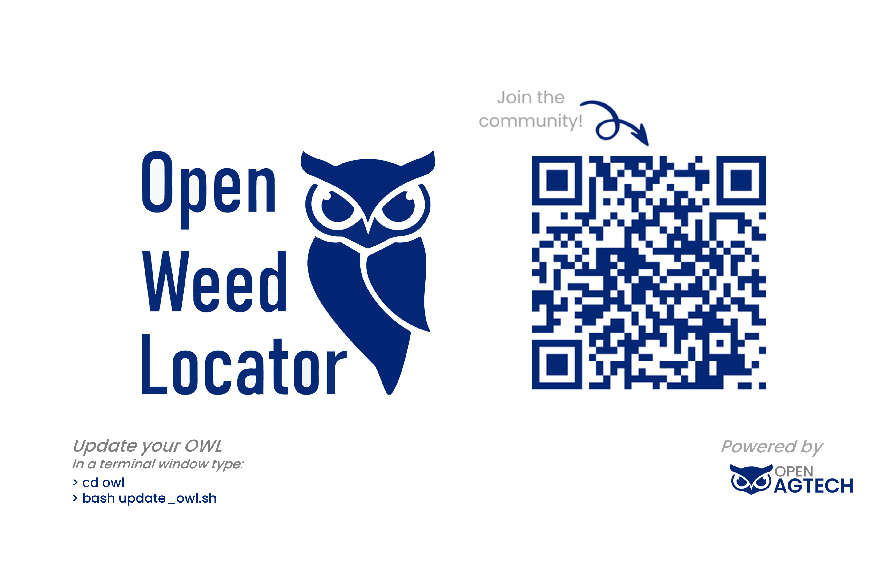
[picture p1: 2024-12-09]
images/owl-background.png

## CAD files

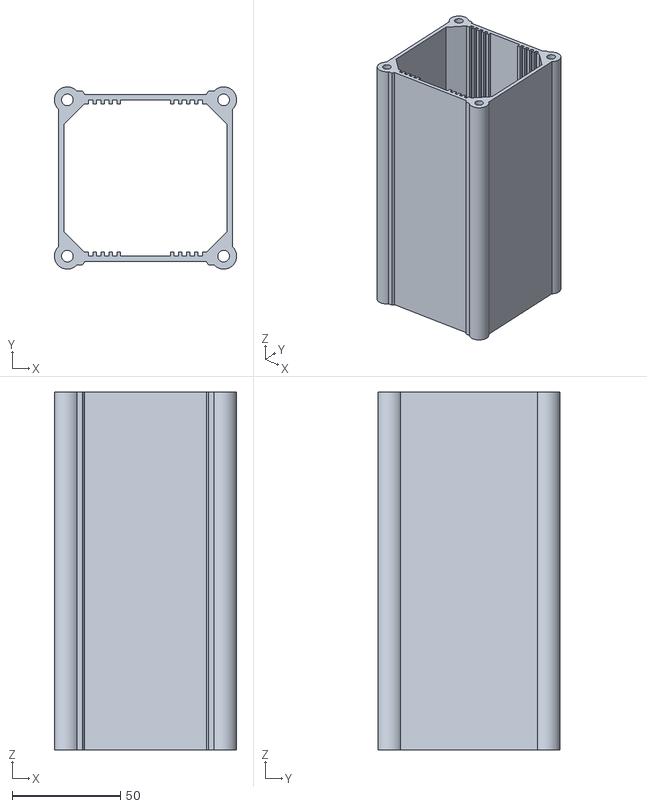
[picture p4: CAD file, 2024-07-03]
3D Models/Compact OWL/Main Body.stl
84.0 x 84.0 x 165.0

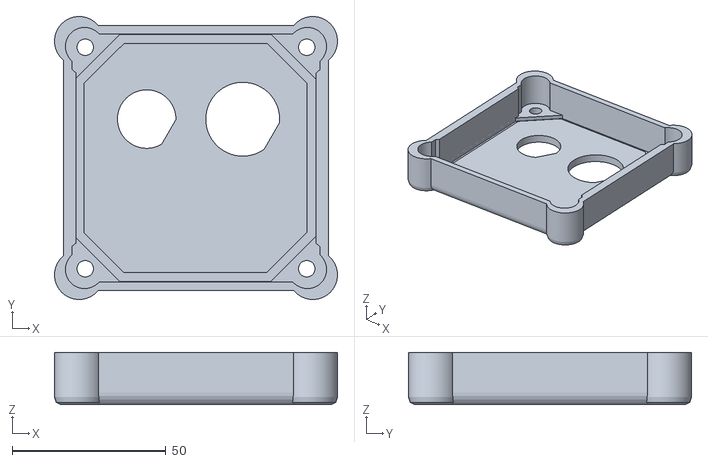
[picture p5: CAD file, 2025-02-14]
3D Models/Compact OWL/Backplate - 2 x Amphenol receptacle.stl
92.0 x 92.0 x 17.0

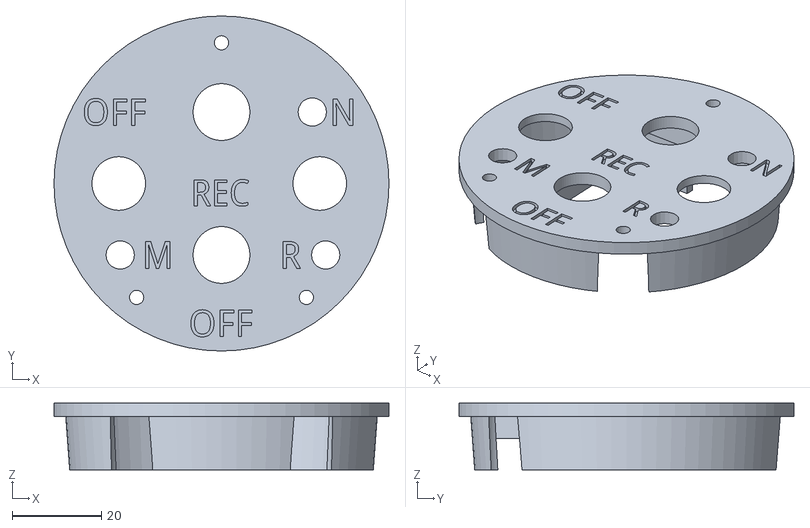
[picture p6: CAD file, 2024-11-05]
3D Models/Controllers/Ute Controller - Top.stl
75.0 x 75.0 x 15.0

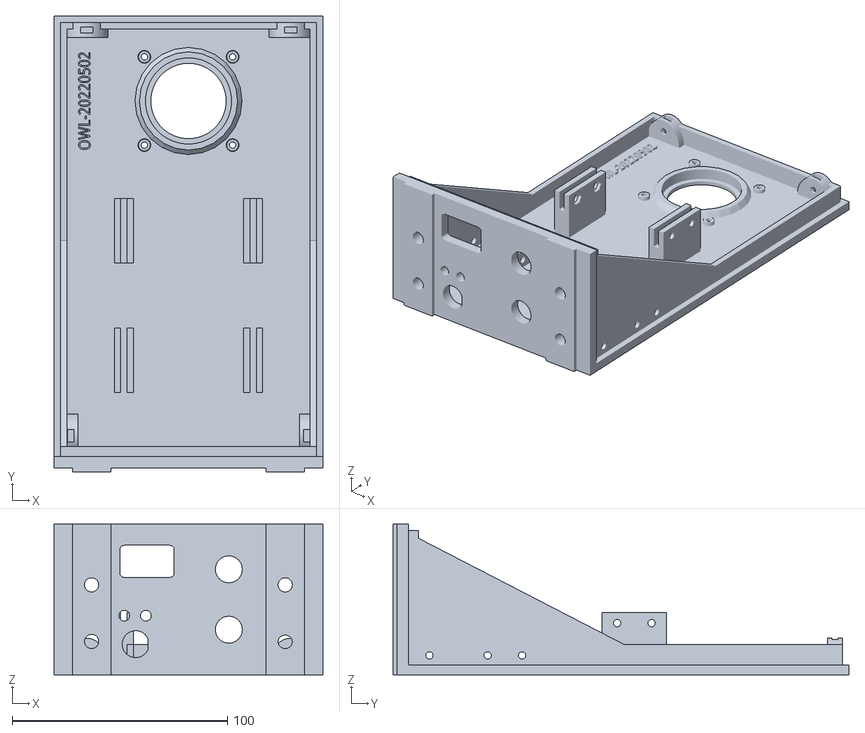
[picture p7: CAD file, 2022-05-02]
3D Models/Original OWL/Enclosure - cable gland.stl
125.0 x 212.0 x 70.0

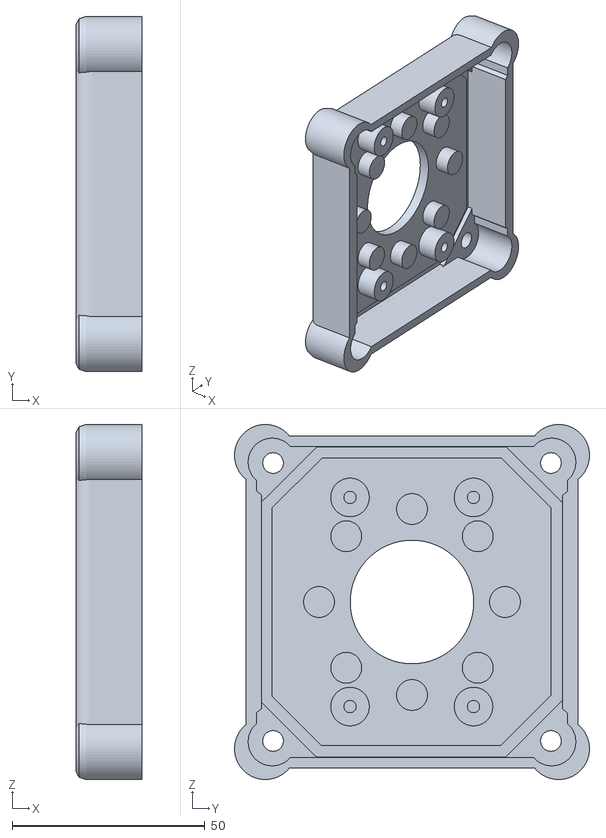
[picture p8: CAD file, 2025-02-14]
3D Models/Compact OWL/Frontplate.stl
17.0 x 92.0 x 92.0

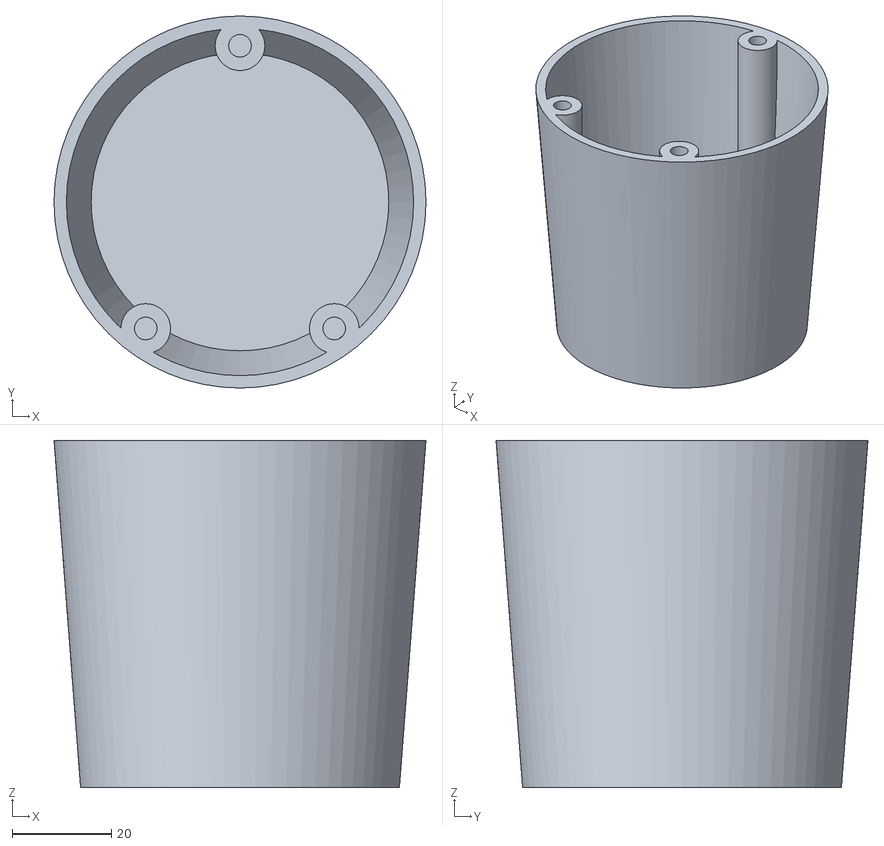
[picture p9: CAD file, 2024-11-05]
3D Models/Controllers/Ute Controller - Base.stl
75.0 x 75.0 x 70.0

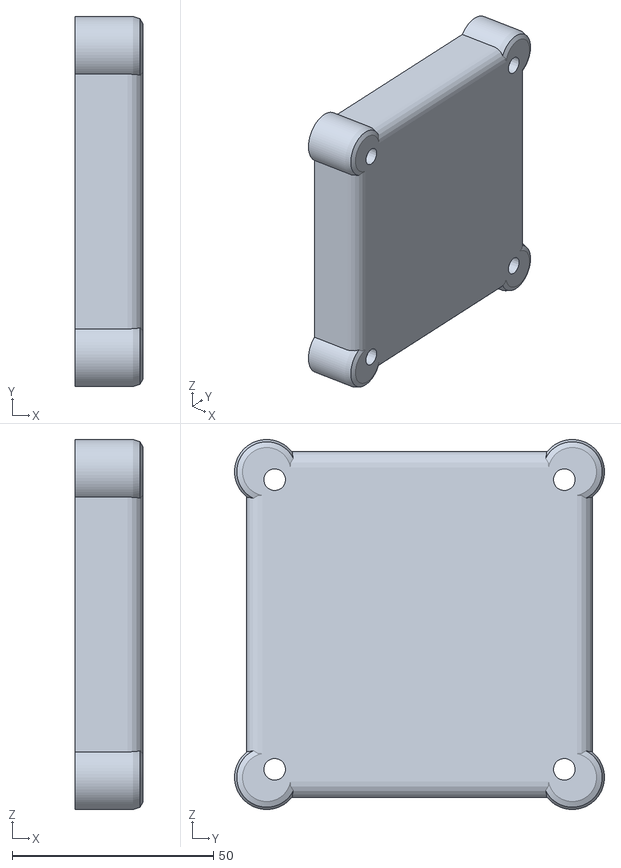
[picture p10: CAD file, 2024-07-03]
3D Models/Compact OWL/Backplate - blank.stl
17.0 x 92.0 x 92.0

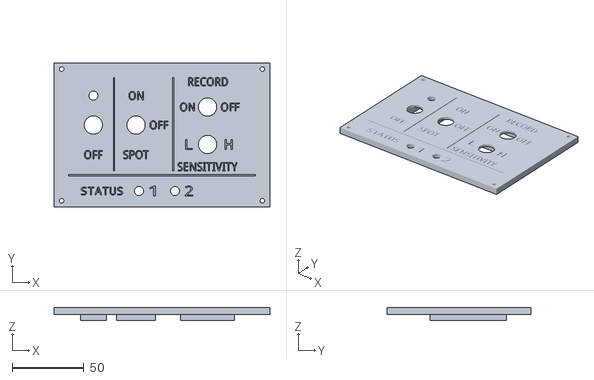
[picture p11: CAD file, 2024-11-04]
3D Models/Controllers/Advanced Controller - Top - Double OWL.stl
150.0 x 99.9 x 9.00

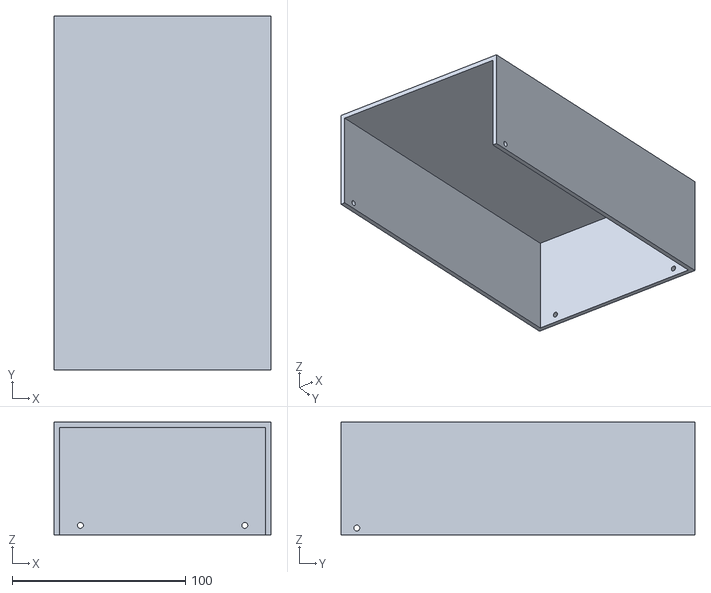
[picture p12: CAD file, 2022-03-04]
3D Models/Original OWL/Enclosure - cover.stl
125.0 x 204.1 x 64.9

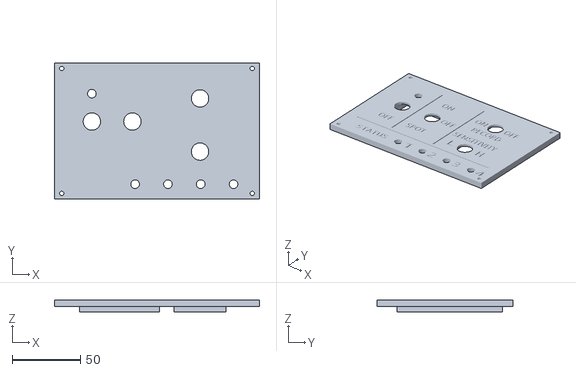
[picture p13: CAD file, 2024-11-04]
3D Models/Controllers/Advanced Controller - Top - 4 OWL.stl
150.0 x 99.9 x 9.00

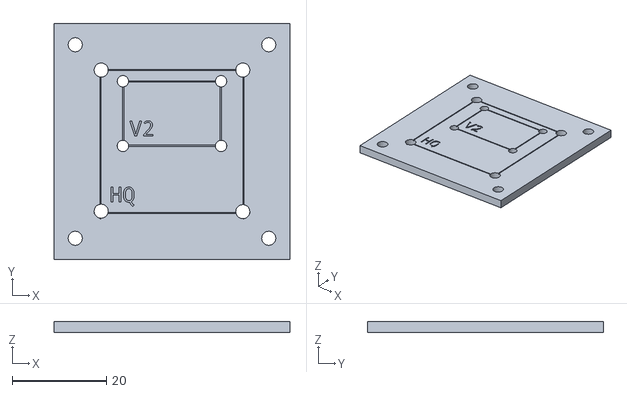
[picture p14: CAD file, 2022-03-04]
3D Models/Original OWL/Camera mount.stl
50.0 x 50.0 x 2.31

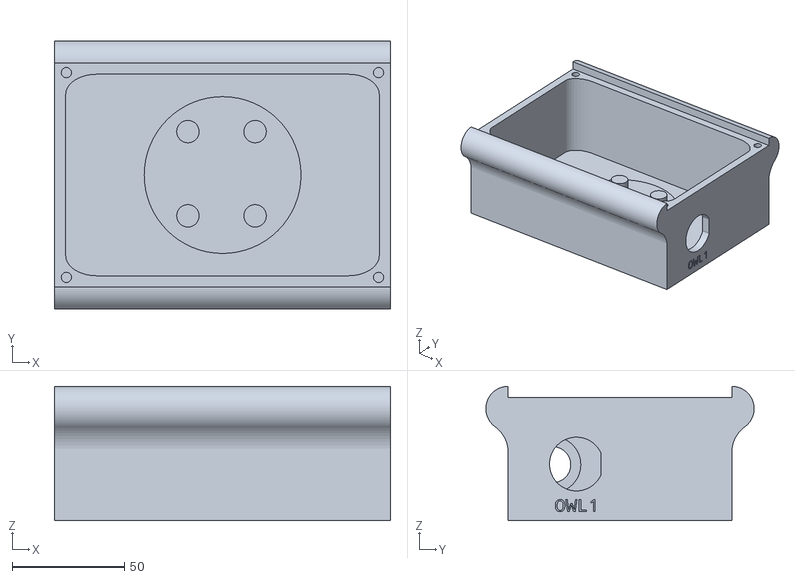
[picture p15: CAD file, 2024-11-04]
3D Models/Controllers/Advanced Controller - Base - Single OWL.stl
150.0 x 119.8 x 60.0

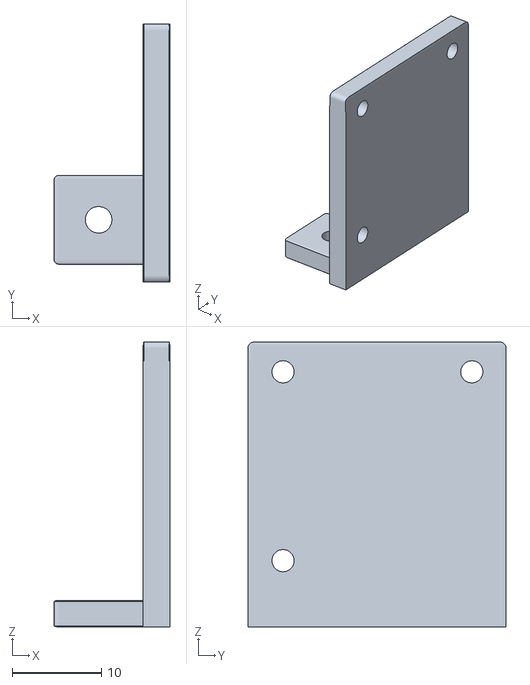
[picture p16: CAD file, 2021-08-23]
3D Models/Original OWL/Voltage regulator mount.stl
13.0 x 29.0 x 32.0

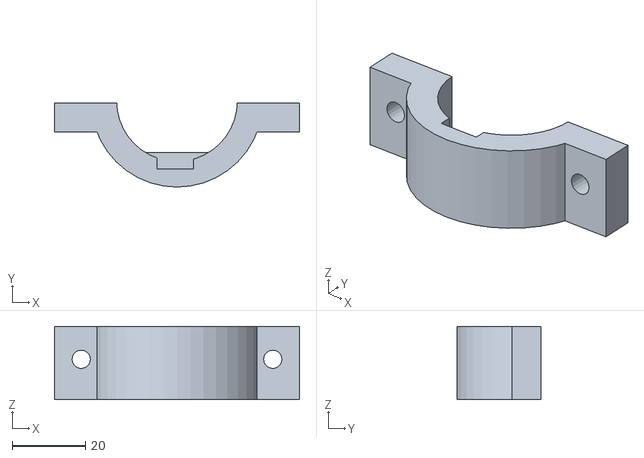
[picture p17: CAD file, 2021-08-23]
3D Models/Original OWL/Solenoid mount - front.stl
67.0 x 23.0 x 20.0

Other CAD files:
3D Models/Original OWL/Enclosure - single connector.stl
3D Models/Compact OWL/Backplate - gland.stl
3D Models/Compact OWL/Backplate - receptacle only.stl
3D Models/Controllers/Advanced Controller - Base - 4 OWL.stl
3D Models/Compact OWL/Backplate - receptacle and ethernet.stl
3D Models/Compact OWL/Camera Mount.stl
3D Models/Compact OWL/Lens Mount.stl
3D Models/Compact OWL/Tray - base.stl
3D Models/Compact OWL/Tray - lens holder.stl
3D Models/Controllers/Advanced Controller - Base - Double OWL.stl
3D Models/Controllers/Advanced Controller - Top - Single OWL.stl
3D Models/Original OWL/Enclosure plug.stl
3D Models/Original OWL/Raspberry Pi mount.stl
3D Models/Original OWL/Relay control board mount.stl
3D Models/Original OWL/Solenoid mount - back.stl
3D Models/Original OWL/Solenoid mount - mid.stl

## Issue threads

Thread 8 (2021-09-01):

STL files as STEP for modification?

rfirth-code, 2021-09-01:
Any chance we could get the .step files for the case and cover that are currently STL downloads?
My 3D printer can't handle the build volume so I was looking to modify for laser cutting instead.
Awesome project!

rfirth-code, 2021-09-01:
@plains203 thanks for the link - do you know if their is any way of downloading this in a 3d format other than STL or OBJ?

plains203, 2021-09-01:
That I don’t know.

geezacoleman, 2021-09-01:
It looks like TinkerCAD doesn't support that conversion, but there are a couple of other ways mentioned [here](https://all3dp.com/2/stl-to-step-how-to-convert-stl-files-to-step/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,to%20upload%20the%20files%20to.&text=From%20there%2C%20you%20can%20select,to%20export%20to%2C%20including%20STEP.), using either Fusion360 or FreeCAD. Hopefully that helps!

If you do end up converting them, open up a pull request and we can add them to the 3D models folder too.

MerbeinRobotics, 2021-09-03:
Hi,  I have the same issue with the size of the cover and case, it's just a bit too big for my Creality Ender 3 3D printer.  But think I can modify the STL file through Fusion 360.  I'll have a go....

But I'm really excited about this project.  I've been working on an autonomous vineyard robot based on the Ardurover/Cube/Mission planner project and the OWL will be perfect for it.    I also wanted to get more familiar with the Raspberry Pi and computer vision and this is the perfect opportunity to do so.

Well done!

Kind Regards,

Stephen

geezacoleman, 2021-09-06:
Thanks Stephen for the feedback! It will be great to see how you use this. Make sure you share the outcome once you're done too and any suggestions for improvements along the way.

Any luck modifying the STL on Fusion 360? @williamtsalter perhaps if you linked the original Tinkercad for the base then it could be ungrouped and more easily adjusted. This length was selected because it only just fit on my Prusa Mk3S.

williamtsalter, 2021-09-06:
@MerbeinRobotics and @geezacoleman, I just had a look at the public model on TinkerCad and you should already be able to ungroup the base for easy modification. It should become a colourful mess when you ungroup. If this isn't the case for you, please let me know as I may have to change the settings for other users.
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

geezacoleman, 2021-09-06:
Thanks @williamtsalter - I just tried that using the link above and the model comes apart nicely as in the image. Ctrl + shift + g to ungroup or there's a button in the top right of the frame.

MerbeinRobotics, 2021-09-07:
Thanks @geezacoleman and @williamtsalter.  After a bit of fiddling with Cura I discovered the case will fit in the Ender 3 if I print it vertically (with the end on the base).  Probably not ideal and I would prefer to print it from the base up.    I have  been able to convert the STL (mesh) file to a solid body in Fusion 360 ready for modification.  My initial thought was to rotate the camera mounts 90 degrees so that I can hopefully shorten the overall length by about 23mm.

geezacoleman, 2021-09-09:
That's good to hear @MerbeinRobotics that it fits - it is quite tall, but hopefully printing it vertically works.

I'll close this issue now as we've addressed the original question, but open up a new issue if you end up shortening it and we can incorporate at short model into the set too.

Closed 2021-09-09.

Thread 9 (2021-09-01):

generate ROS nodes for OWL

geezacoleman, 2021-09-01:
Improve cross compatibility with the fairly widely accepted standard for ag robotics. I'm very unfamiliar with ROS (though really should be better!), so this is a good project if someone wants to take it on.

geezacoleman, 2022-03-22:
Using ROS nodes for the OWL would be a big improvement in functionality, modularity and repeatability, but could throw [some issues with Raspbian vs. Ubuntu](https://roboticsbackend.com/using-ros-on-raspberry-pi-best-practices/).

Will continue looking into it and changing the system over.

EchelonMirror, 2022-09-16:
We can have a chat about this in a couple of months and see how we can help with a ROS2 port (ROS2 is a heck of a lot better).

geezacoleman, 2024-12-16:
That would be great - let me know how it goes and if you have any questions. The main objective would be to allow OWL to be better integrated with field robots instead of just running as a simple python script.

RtJinxuWang, 2025-04-27:
> That would be great - let me know how it goes and if you have any questions. The main objective would be to allow OWL to be better integrated with field robots instead of just running as a simple python script.

Sorry, I was busy with my own precise spraying project some time ago, so I rewrote a system based on ros by myself. I currently only have an nvidia device. When I have time later, I will try to encapsulate OWL into ros on an nvidia device. Besides, I have relatively little knowledge about hardware. I would like to ask you, for example, what types of cameras do the precision spraying company bilberry in France and John Deere's see and spray use? I'm currently using an industrial camera, but it's too severely affected by light!

EchelonMirror, 2025-04-27:
What light issues are you having you having with the industrial camera?

RtJinxuWang, 2025-04-28:
> What light issues are you having you having with the industrial camera?

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
This picture has a particularly poor imaging effect in the shadow state

geezacoleman, 2025-04-30:
> Sorry, I was busy with my own precise spraying project some time ago, so I rewrote a system based on ros by myself. I currently only have an nvidia device. When I have time later, I will try to encapsulate OWL into ros on an nvidia device. Besides, I have relatively little knowledge about hardware. I would like to ask you, for example, what types of cameras do the precision spraying company bilberry in France and John Deere's see and spray use? I'm currently using an industrial camera, but it's too severely affected by light!

That's awesome - would be nice to see OWL on an NVIDIA device with ROS. Let me know how you go.

I'm unsure of the specifics of the hardware those companies use, and they unfortunately don't like to share and I also haven't had the opportunity to pull one apart! For research we have used FLIR Blackfly and LucidVision TritonS machine vision cameras. All struggle with harsh shadows unfortunately, which is why many companies invest in strobe or LED lighting.

The image above though, the information in the shadows is still there, so training a model on the image would likely still work quite well, it would just need data from images with shadows.

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

Closed 2024-11-14.

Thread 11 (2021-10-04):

stronger camera mounts

geezacoleman, 2021-10-04:
Issues with camera mount breaking/weaknesses have become clear. Need a redesign of the mounting hardware to make it sturdier and potentially shorter to fit on smaller print plates.

williamtsalter, 2022-02-28:
I have now printed several updated enclosures that use standoffs to hold the HQ camera in place. These are considerably more robust than the original design. I will have to get some new photos for the hardware assembly instructions in the readme and update the 3d print files. I will do this later this week then close this issue.

williamtsalter, 2022-03-04:
I have now updated the read me and the stl files with the stronger camera mount

Closed 2022-03-04.

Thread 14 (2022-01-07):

Error with file logger

dtms6, 2022-01-07:
Having assembled an OWL and installed the software.I continue to receive the following error once having focused the camera:

FileNotFoundError: [Errno 2] No such file or directory: 'logs/20220108-065504_weed_log.txt'

The error occurs almost instantaneously and kills the program.
There appears to be an issue with inability to write and then recall a file log in the logger directory.

I haven't altered any code and have reinstalled/updated the OWL software just in case, but the error remains.

Would appreciate some guidance.

The output is as follows:

(owl) pi@owl:~ $ ~/owl/./greenonbrown.py
linux
[INFO] Setting up nozzles...
Solenoid 0 OFF
Solenoid 1 OFF
Solenoid 2 OFF
Solenoid 3 OFF
[INFO] Setup complete. Starting spraying.
Solenoid 3 ON
Traceback (most recent call last):
  File "/home/pi/owl/./greenonbrown.py", line 291, in hoot
    self.controller.receive(nozzle=i, delay=delay, timeStamp=sprayTime, duration=sprayDur)
  File "/home/pi/owl/relay_control.py", line 132, in receive
    self.logger.log_line(line)
  File "/home/pi/owl/logger.py", line 17, in log_line
    with open(self.saveDir, 'a+') as file:
FileNotFoundError: [Errno 2] No such file or directory: 'logs/20220108-065030_weed_log.txt'

During handling of the above exception, another exception occurred:

Traceback (most recent call last):
  File "/home/pi/owl/./greenonbrown.py", line 417, in <module>
    minArea=10)
  File "/home/pi/owl/./greenonbrown.py", line 325, in hoot
    self.logger.log_line("[CRITICAL ERROR] STOPPED: {}".format(e))
  File "/home/pi/owl/logger.py", line 17, in log_line
    with open(self.saveDir, 'a+') as file:
FileNotFoundError: [Errno 2] No such file or directory: 'logs/20220108-065030_weed_log.txt'

geezacoleman, 2022-01-07:
Thanks for putting one together and for the heads up!

It looks like this might be an issue with the absolute vs. relative path references where it's looking for `logs/20220108-065030_weed_log.txt` from `(owl) pi@owl:~ $ ~/owl/./greenonbrown.py` where it's looking for that log file in the root directory.

If you try running it from the owl directory, does it work?
`> cd owl`
`> ./greenonbrown.py`

I'll make a quick change to the code to fix it if so.

geezacoleman, 2022-01-07:
Thanks for putting one together and for the heads up!

It looks like this might be an issue with the absolute vs. relative path references where it's looking for `logs/20220108-065030_weed_log.txt` from `(owl) pi@owl:~ $ ~/owl/./greenonbrown.py` where it's looking for that log file in the root directory.

If you try running it from the owl directory, does it work?
`> cd owl`
`> ./greenonbrown.py`

I'll make a quick change to the code to fix it if so.

geezacoleman, 2022-01-07:
Thanks for putting one together and for the heads up!

It looks like this might be an issue with the absolute vs. relative path references where it's looking for `logs/20220108-065030_weed_log.txt` from `(owl) pi@owl:~ $ ~/owl/./greenonbrown.py` where it's looking for that log file in the root directory.

If you try running it from the owl directory, does it work?
`> cd owl`
`> ./greenonbrown.py`

I'll make a quick change to the code to fix it if so.

dtms6, 2022-01-08:
Yes. That resolves the issue! Works a treat.
I'll share some photos of the unit.

geezacoleman, 2022-01-08:
Glad that worked out! I'll leave this issue open for the moment so I can fix it up next week.

Looking forward to see how the unit ended up.

geezacoleman, 2022-01-10:
@dtms6 this should now be fixed - you'll just need to update the owl folder with the latest version of the repo.

dtms6, 2022-01-10:
Yes it fixed the problem. Updated the files and works like a treat. Thanks.

Closed 2022-01-10.

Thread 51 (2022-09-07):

Software issues focusing camera

manninb, 2022-09-07:
Hi,
I'm not able to get an image from the camera up after following the instructions, wondering if anyone can offer help. see below.

pi@raspberrypi:~ $ ps-C greenonbrown.py
bash: ps-C: command not found
pi@raspberrypi:~ $ ps -C greenonbrown.py
  PID TTY          TIME CMD
  533 ?        01:03:14 greenonbrown.py
pi@raspberrypi:~ $ sudo kill 533
pi@raspberrypi:~ $ ~/owl/./greenonbrown.py --show-display
linux
/home/pi/.virtualenvs/owl/lib/python3.7/site-packages/gpiozero/devices.py:290: PinFactoryFallback: Falling back from rpigpio: No module named 'RPi'
  'Falling back from %s: %s' % (name, str(e))))
/home/pi/.virtualenvs/owl/lib/python3.7/site-packages/gpiozero/devices.py:290: PinFactoryFallback: Falling back from lgpio: No module named 'lgpio'
  'Falling back from %s: %s' % (name, str(e))))
/home/pi/.virtualenvs/owl/lib/python3.7/site-packages/gpiozero/devices.py:290: PinFactoryFallback: Falling back from rpio: No module named 'RPIO'
  'Falling back from %s: %s' % (name, str(e))))
/home/pi/.virtualenvs/owl/lib/python3.7/site-packages/gpiozero/devices.py:290: PinFactoryFallback: Falling back from pigpio: No module named 'pigpio'
  'Falling back from %s: %s' % (name, str(e))))
/home/pi/.virtualenvs/owl/lib/python3.7/site-packages/gpiozero/devices.py:285: NativePinFactoryFallback: Falling back to the experimental pin factory NativeFactory because no other pin factory could be loaded. For best results, install RPi.GPIO or pigpio. See https://gpiozero.readthedocs.io/en/stable/api_pins.html for more information.
  warnings.warn(NativePinFactoryFallback(native_fallback_message))
[INFO] Setting up nozzles...
Solenoid 0 OFF
Solenoid 1 OFF
Solenoid 2 OFF
Solenoid 3 OFF
[INFO] Setup complete. Starting spraying.

geezacoleman, 2022-09-07:
Thanks @manninb, based on this [thread](https://forums.raspberrypi.com/viewtopic.php?t=275387), it looks like it could be a Python2 vs Python3 issue for RPi.GPIO

```
sudo apt update
sudo apt install python3-rpi.gpio
```

Let us know how that goes - we will need to update the instructions/requirements.txt file if so!

manninb, 2022-09-07:
It didn't seem to work I put the script in the terminal window an it seemed to run. see below

I closed the unit down and restarted it but could still not get the camera vision.

do you have any other ideas or suggestions as to where I went wrong

pi@raspberrypi:~ $ sudo apt update
Get:1 http://raspbian.raspberrypi.org/raspbian buster InRelease [15.0 kB]
Get:2 http://archive.raspberrypi.org/debian buster InRelease [32.6 kB]
Get:3 http://raspbian.raspberrypi.org/raspbian buster/main armhf Packages [13.0 MB]
Get:4 http://archive.raspberrypi.org/debian buster/main armhf Packages [392 kB]
Get:5 http://raspbian.raspberrypi.org/raspbian buster/contrib armhf Packages [58.8 kB]
Get:6 http://raspbian.raspberrypi.org/raspbian buster/non-free armhf Packages [104 kB]
Fetched 13.6 MB in 47s (287 kB/s)                                      
Reading package lists... Done
Building dependency tree
Reading state information... Done
196 packages can be upgraded. Run 'apt list --upgradable' to see them.
N: Repository 'http://raspbian.raspberrypi.org/raspbian buster InRelease' changed its 'Suite' value from 'stable' to 'oldstable'
N: Repository 'http://archive.raspberrypi.org/debian buster InRelease' changed its 'Suite' value from 'testing' to 'oldstable'
pi@raspberrypi:~ $ sudo apt install python3-rpi.gpio
Reading package lists... Done
Building dependency tree
Reading state information... Done
python3-rpi.gpio is already the newest version (0.7.0-0.1~bpo10+4).
The following package was automatically installed and is no longer required:
  python-colorzero
Use 'sudo apt autoremove' to remove it.
0 upgraded, 0 newly installed, 0 to remove and 196 not upgraded.
pi@raspberrypi:~ $

manninb, 2022-09-07:
Further to the above this is the script I get when I attempt get the camera view

pi@raspberrypi:~ $ ps -c greenonbrown.py
error: unknown user-defined format specifier "nbrown.py"

Usage:
 ps [options]

 Try 'ps --help <simple|list|output|threads|misc|all>'
  or 'ps --help <s|l|o|t|m|a>'
 for additional help text.

For more details see ps(1).
pi@raspberrypi:~ $ ps -C greenonbrown.py
  PID TTY          TIME CMD
  526 ?        01:09:19 greenonbrown.py
pi@raspberrypi:~ $ sudo kill 526
pi@raspberrypi:~ $  ~/owl/./greenonbrown.py --show-display
linux
/home/pi/.virtualenvs/owl/lib/python3.7/site-packages/gpiozero/devices.py:290: PinFactoryFallback: Falling back from rpigpio: No module named 'RPi'
  'Falling back from %s: %s' % (name, str(e))))
/home/pi/.virtualenvs/owl/lib/python3.7/site-packages/gpiozero/devices.py:290: PinFactoryFallback: Falling back from lgpio: No module named 'lgpio'
  'Falling back from %s: %s' % (name, str(e))))
/home/pi/.virtualenvs/owl/lib/python3.7/site-packages/gpiozero/devices.py:290: PinFactoryFallback: Falling back from rpio: No module named 'RPIO'
  'Falling back from %s: %s' % (name, str(e))))
/home/pi/.virtualenvs/owl/lib/python3.7/site-packages/gpiozero/devices.py:290: PinFactoryFallback: Falling back from pigpio: No module named 'pigpio'
  'Falling back from %s: %s' % (name, str(e))))
/home/pi/.virtualenvs/owl/lib/python3.7/site-packages/gpiozero/devices.py:285: NativePinFactoryFallback: Falling back to the experimental pin factory NativeFactory because no other pin factory could be loaded. For best results, install RPi.GPIO or pigpio.
  warnings.warn(NativePinFactoryFallback(native_fallback_message))
[INFO] Setting up nozzles...
Solenoid 0 OFF
Solenoid 1 OFF
Solenoid 2 OFF
Solenoid 3 OFF
[INFO] Setup complete. Starting spraying.
Solenoid 0 ON
Traceback (most recent call last):
  File "/home/pi/owl/./greenonbrown.py", line 285, in hoot
    self.controller.receive(nozzle=i, timeStamp=sprayTime, duration=sprayDur)
  File "/home/pi/owl/relay_control.py", line 132, in receive
    self.logger.log_line(line)
  File "/home/pi/owl/logger.py", line 17, in log_line
    with open(self.saveDir, 'a+') as file:
FileNotFoundError: [Errno 2] No such file or directory: 'logs/20220907-160300_weed_log.txt'

During handling of the above exception, another exception occurred:

Traceback (most recent call last):
  File "/home/pi/owl/./greenonbrown.py", line 406, in <module>
    minArea=10)
  File "/home/pi/owl/./greenonbrown.py", line 319, in hoot
    self.logger.log_line("[CRITICAL ERROR] STOPPED: {}".format(e))
  File "/home/pi/owl/logger.py", line 17, in log_line
    with open(self.saveDir, 'a+') as file:
FileNotFoundError: [Errno 2] No such file or directory: 'logs/20220907-160300_weed_log.txt'
pi@raspberrypi:~ $ ^C

geezacoleman, 2022-09-07:
Thanks for trying that - I think I've worked out why the `PinFactoryFallback: Falling back from rpigpio: No module named 'RPi'` error is occurring. While it is just a warning from gpiozero, the greenonbrown.py script will only start a PiCamera instance if it can find RPi.GPIO, otherwise it defaults to a USB webcam, which is why the camera isn't starting.

This error PinFactoryFallback warning occurs when RPi.GPIO isn't installed - in this case it looks like it isn't installed in the `owl` virtual environment. Assuming you've already made an `owl` environment (looks like that's the case), you'll need to type the following commands:
```
workon owl
pip3 install rpi.gpio

```
This is based on a comment in the [gpiozero docs](https://gpiozero.readthedocs.io/en/stable/faq.html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) FAQs about this warning.

You can also do:
```
workon owl
pip install -r requirements.txt
```
This error should have been fixed previously - make sure you're using the most up to date version of owl, by re-cloning the repository. If that doesn't work, to overcome the `FileNotFoundError` you'll need to launch `greenonbrown.py` from the `owl` directory.

So if you:
```
cd owl
~/owl/./greenonbrown.py --show-display
```

geezacoleman, 2022-09-08:
Has this fixed the camera/logging issues? If so I'll close this issue.

Wifi is probably better addressed by the wider Raspberry Pi community, there could be a few different reasons for that.

manninb, 2022-09-12:
thank, I have got wi fi working for the time being ran the the last lot of script.

pi@raspberrypi:~ $ workon owl
(owl) pi@raspberrypi:~ $ pip3 install rpi.gpio
Looking in indexes: https://pypi.org/simple, https://www.piwheels.org/simple
Collecting rpi.gpio
  Downloading https://www.piwheels.org/simple/rpi-gpio/RPi.GPIO-0.7.1-cp37-cp37m-linux_armv7l.whl (47 kB)

Installing collected packages: rpi.gpio
Successfully installed rpi.gpio-0.7.1
WARNING: You are using pip version 21.1.2; however, version 22.2.2 is available.
You should consider upgrading via the '/home/pi/.virtualenvs/owl/bin/python -m pip install --upgrade pip' command.
(owl) pi@raspberrypi:~ $ workon owl
(owl) pi@raspberrypi:~ $ pip install -r requirements.txt
ERROR: Could not open requirements file: [Errno 2] No such file or directory: 'requirements.txt'
WARNING: You are using pip version 21.1.2; however, version 22.2.2 is available.
You should consider upgrading via the '/home/pi/.virtualenvs/owl/bin/python -m pip install --upgrade pip' command.
(owl) pi@raspberrypi:~ $
(owl) pi@raspberrypi:~ $ cd owl
(owl) pi@raspberrypi:~/owl $ ~/owl/.greenonbrown.py --show-display
bash: /home/pi/owl/.greenonbrown.py: No such file or directory
(owl) pi@raspberrypi:~/owl $

Attempted the camera view procedure again (twice) but was unable to get a view of the camera.

got these results
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
manninb, 2022-09-16:
ps can you tell me the function of the commands below?

cd owl
pip install -r requirements.txt

geezacoleman, 2022-09-16:
The version downloaded from the site is the one that needs updating as mentioned above. It was the original software we had when the OWL was first launched but it is old and has lots of flaws. It works if you run greenonbrown.py from the OWL directory but doesn't if you run it from anywhere else. So I wouldn't redownload/reimage any cards again, just use this one. The version from the download is about a year behind the one you get from updating it.

To get this working you need to :
1. get the latest software from GitHub and save it to a new owl folder on the card, this is what I mean by 'updating'. This is done by following the [Update OWL procedure](https://github.com/geezacoleman/OpenWeedLocator#updating-owl).
2. This procedure guides you through installing all the required libraries/supporting software to avoid the rpi.gpio issue above.
3. Once you have carefully followed this you should have everything working fine.

`pip install -r requirements.txt` installs all the listed packages within the requirements.txt file. It's a faster way of adding all the various packages needed.

`cd` means change directory. It moves into the folder you specify. E.g. `cd owl` moves you into the owl folder if it exists.

geezacoleman, 2022-10-05:
Were you able to fix this @manninb? I might close this if so.

manninb, 2022-10-05:
Thanks, I have been called away to other jobs, but will be back onto this, so far no luck.

manninb, 2022-10-07:
thanks, I have got this to work, This is probably a dumb question but  can you give me the command to go from
(owl) pi@raspberrypi:~/owl $
back to
(owl) pi@raspberrypi:~ $

geezacoleman, 2022-10-07:
Ok great! What did you have to do differently?

Sure thing, just type:
`(owl) pi@raspberrypi: $ cd ..` (should have a space between the `cd` and the two `.`)

manninb, 2022-10-07:
I'm not sure exactly, I may not have been going back to the raspberry from the owl directory if that makes sense. I will try a few other units and see how it goes. There was quite a bit of interest in the OWL at the Nowley field day.

geezacoleman, 2022-10-07:
That's good to hear thanks for talking about it - feel free to write up a summary in the discussions page for any feedback/lessons learned etc.

I'll close this issue now as it's been resolved.

Closed 2022-10-07.

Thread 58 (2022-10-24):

focusing issue

manninb, 2022-10-24:
Had an issue focusing after many successful attempts. I updated software  first but then had trouble getting the PID number, see below.

 pi@raspberrypi:~ $ cd ~
pi@raspberrypi:~ $ mv owl owl-old
pi@raspberrypi:~ $ git clone https://github.com/geezacoleman/OpenWeedLocator
Cloning into 'OpenWeedLocator'...
remote: Enumerating objects: 366, done.
remote: Counting objects: 100% (247/247), done.
remote: Compressing objects: 100% (131/131), done.
remote: Total 366 (delta 163), reused 160 (delta 114), pack-reused 119
Receiving objects: 100% (366/366), 2.87 MiB | 5.26 MiB/s, done.
Resolving deltas: 100% (187/187), done.
pi@raspberrypi:~ $ mv OpenWeedLocator owl
pi@raspberrypi:~ $ cd ~/owl
pi@raspberrypi:~/owl $ pip install -r requirements.txt
Defaulting to user installation because normal site-packages is not writeable
Looking in indexes: https://pypi.org/simple, https://www.piwheels.org/simple
Requirement already satisfied: numpy in /home/pi/.local/lib/python3.7/site-packages (from -r requirements.txt (line 3)) (1.21.6)
Requirement already satisfied: imutils in /home/pi/.local/lib/python3.7/site-packages (from -r requirements.txt (line 4)) (0.5.4)
Requirement already satisfied: gpiozero in /usr/lib/python3/dist-packages (from -r requirements.txt (line 5)) (1.6.2)
Requirement already satisfied: pandas in /home/pi/.local/lib/python3.7/site-packages (from -r requirements.txt (line 6)) (1.3.5)
Requirement already satisfied: glob2 in /home/pi/.local/lib/python3.7/site-packages (from -r requirements.txt (line 7)) (0.7)
Requirement already satisfied: RPi.GPIO in /usr/lib/python3/dist-packages (from -r requirements.txt (line 8)) (0.7.0)
Requirement already satisfied: picamera in /usr/lib/python3/dist-packages (from -r requirements.txt (line 9)) (1.13)
Requirement already satisfied: pytz>=2017.3 in /home/pi/.local/lib/python3.7/site-packages (from pandas->-r requirements.txt (line 6)) (2022.5)
Requirement already satisfied: python-dateutil>=2.7.3 in /home/pi/.local/lib/python3.7/site-packages (from pandas->-r requirements.txt (line 6)) (2.8.2)
Requirement already satisfied: six>=1.5 in /usr/lib/python3/dist-packages (from python-dateutil>=2.7.3->pandas->-r requirements.txt (line 6)) (1.12.0)
WARNING: You are using pip version 21.1.2; however, version 22.3 is available.
You should consider upgrading via the '/usr/bin/python3 -m pip install --upgrade pip' command.
pi@raspberrypi:~/owl $ chmod a+x greenonbrown.py
pi@raspberrypi:~/owl $ chmod a+x owl_boot.sh
pi@raspberrypi:~/owl $ cd ..
pi@raspberrypi:~ $ ps -C greenonbrown.py
  PID TTY          TIME CMD
pi@raspberrypi:~ $

geezacoleman, 2022-10-24:
The `ps -C greenonbrown.py` command will just list anything that is running with 'greenonbrown.py' in the name, so here it looks like `greenonbrown.py` isn't running so you can continue with the focusing by running `./greenonbrown.py -- show-display`. A bit more detail below on why we need to do this.

I also noticed that you need activate the `owl` virtual environment, before installing the `requirements.txt` file. At the moment, those packages have been installed outside of the virtual environment so they won't be accessed when `greenonbrown.py` runs. To fix that run:
```
pi@raspberrypi:~ $ cd ~/owl
pi@raspberrypi:/owl $ workon owl
(owl) pi@raspberrypi:/owl $ pip install -r requirements.txt
```

Before running the pip install command, make sure you see `(owl)` at the start of the line. This tells you that you're in the owl virtual environment.

For a bit more detail on the `ps -C`, the reason we do this is that when `greenonbrown.py` runs on startup it restricts access to the camera to only one program at once. Because it operates in the background, you can't just use Terminal to stop it. So if we want to rerun it, we need to make sure it isn't running in the background by finding its program ID (PID) with the `ps -C` command and then using `sudo kill PID`.

In your case, it looks like there isn't a program called `greenonbrown,py` running, so it won't appear when you enter that command. This means you can just continue with the setup, but definitely need to fix the installation of `requirements.txt` into the right virtual environment.

geezacoleman, 2022-10-24:
I realised this wasn't particularly clear in the updating instructions and I think it was resulting in both @manninb and @MerbeinRobotics issues with access to the RPi.GPIO package.

This has hopefully been made clearer in this commit: https://github.com/geezacoleman/OpenWeedLocator/commit/d62af8c45de26da92276d695c37f9982cb262f0f

manninb, 2022-10-25:
Got this sorted. Thanks for your help.

Closed 2022-10-25.

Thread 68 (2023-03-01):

moving to 50 cm nozzle.

manninb, 2023-03-01:
What would be needed to operate the systems for a 50cm nozzle spacing? Does anybody have the capacity to do the coding if required. Most commercial spraying works on 50 cm spacing.

geezacoleman, 2023-03-01:
There are a couple of ways to change this:

1. You could raise the height of the camera to 2m so that four lanes cover 50cm each, but I don't think the resolution will be high enough for good performance on small weeds.
2. Best option is to change `nozzleNum=4` to `nozzleNum=2` and leave the OWL at 1m height. The OWL will only use the first two values in the dictionary that maps the nozzle to the pin on the Raspberry Pi that turns it on. So just make sure you connect the two solenoids to those pins.

```
      # nozzleDict maps the reference nozzle number to a boardpin on the embedded device
        self.nozzleDict = {
            0: 13,         <- it will only use these first two pins
            1: 15,         <- and this one
            2: 16,
            3: 18
        }
```

The `nozzleNum` value is found in `greenonbrown.py` [Line 605](https://github.com/geezacoleman/OpenWeedLocator/blob/main/greenonbrown.py#L605):

```
    owl = Owl(videoFile=args.video_file,
              show_display=args.show_display,
              recording=args.recording,
              exgMin=25,
              exgMax=200,
              hueMin=39,
              hueMax=83,
              saturationMin=50,
              saturationMax=220,
              brightnessMin=60,
              brightnessMax=190,
              resolution=(416, 320),
              nozzleNum=2,                                   <-- this is what you want to change from 4 to 2 (or however many you like)
              framerate=args.framerate,
              exp_mode=args.exp_mode,
              exp_compensation=args.exp_compensation,
              awb_mode=args.awb_mode,
              sensor_mode=args.sensor_mode,
              parameters_json=None
              )

```

geezacoleman, 2023-03-06:
Keep me posted about how this goes @manninb! Would be great to get some videos/photos of the 50cm nozzle setup. I'll close it for now, but feel free to reopen/add more comments if needed.

geezacoleman, 2023-12-02:
That sounds like an interesting use case, would be great if you can share some photos of the completed setup over in the community builds page once you're done!

What specific issues were you having with changing nozzle number?

If it's just one nozzle, change the `nozzleNum=4` parameter on [Line 528](https://github.com/geezacoleman/OpenWeedLocator/blob/be7b979907b8f94b745fa0090c3ff126017f3f3a/owl.py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) in `owl.py` to 1. That way the image will be divided into a single zone and only activate one nozzle.

The `nozzleDict` I talk about above just maps each zone within the image, to a GPIO pin on the Pi. These pins are connected to the relay control board. So if the wrong GPIO number is used because the mapping is incorrect, then the wrong pin is activated and the relay control board probably won't activate, or perhaps the wrong section is activated. As mentioned above the system will only use the first nozzle in the dictionary, but to be certain, you can delete the other parts of the dictionary so it will be

```python
self.nozzleDict = {
            0: 13        # it will only use this pin
        }
```

Just make sure the wire from GPIO 13 is connected. You can copy this code in exactly as it is here to replace the dictionary starting [Line 114 in `owl.py`](https://github.com/geezacoleman/OpenWeedLocator/blob/be7b979907b8f94b745fa0090c3ff126017f3f3a/owl.py#L114-L120)  if that helps.

I've tested this on my own laptop (not OWL device though) and it seems to work, but let me know how you go and if you have any more questions.

Kmrfarmsinc, 2023-12-02:
So, I was able to find the owl.py doc to change the number of nozzles to 1 and the self NozzleDict to only read 0: 13, but when I try and run it the program says 0 nozzles when starting up through the terminal. Also, I had the camera working but it randomly shut off after about 20 seconds from running the program. Don’t know if I deleted more than I should or what but these are the pictures of the terminal and the owl.py changes.
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

geezacoleman, 2023-12-02:
In Python things are generally 0 indexed, so they start counting from 0 not 1. I carried this over into the nozzle numbering on the display (hence Nozzle 0) appears, but that just means the first nozzle, not that there are zero nozzles operating. I think I'll update that for the label above each nozzle, because it isn't entirely clear. This means it is working correctly.

I would recommend running `./owl.py --show-display --exp-mode 'auto'` and see if it closes after 20s or not. I think in the focusing mode it may be running into issues with the almost entirely dark image and the division by 0. In your dictionary you do have an unnecessary comma after 13. So I would delete that too and try again.

There is potentially an unseen bug there somewhere too, but hard to say what just yet!

geezacoleman, 2023-12-04:
Improvements to some of these issues have been made in #103.

Kmrfarmsinc, 2023-12-11:
Having a problem again with the camera feed cutting out. I was able to get the PID, kill that program, get the camera to pop up but it will turn off after 10-20 seconds. Any solution?

geezacoleman, 2023-12-11:
A few questions, which should hopefully narrow it down:
* Similar to above, are you able to provide a screenshot of how you are running it in Terminal and when it fails?
* Are you using just the default green-on-brown detection mode?
* Have you checked the power cables and camera cable to make sure they are connected securely? I would recommend power it over the GPIO pins instead of the USB-C. The USB-C has caused me to have really difficult to diagnose issues before.
* Could you include an image of the hardware too?
* Did you start with the OWL image file and have you updated it recently with `update_owl.sh`?

Kmrfarmsinc, 2023-12-11:
Yes I am using the default green-on-brown detection mode.

The power cord are all good, tested those myself.

I see the GPIO pins but I have the expansion board that goes in those pins. I am going to include the pictures of the hardware.

The camera will turn on and remain on. The problem I found is that I turned my phone camera on and was moving it closer and further away to try and get a detection. I got the camera to pick it up but when i get about 20 cm away from the lens, its shut down. It makes me think it is a sensitivity issue but im not sure.

Im using a HD Raspberry Pi with the ribbon cable.
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

geezacoleman, 2023-12-11:
Ok thanks for sharing the hardware setup - as you say, power looks a lot more robust than the USB-C adapter, so I don't think that should be an issue. When you say you move the phone camera closer/further away, is that like a green object or similar to test it? If you're moving the Pi HD camera and it cuts out, I'm guess that might be a cable issue then. In either case, I'd double check the camera ribbon connection. I have had similar issues previously with old cables that have been bent too much.

For the software, do you have the latest version of the OWL software? I ask because we had this issue from some buggy code a while back but have since fixed it. To diagnose the software - can you leave it running with no detections being made? There might be an issue running only one detection zone and detections falling outside that.

There shouldn't be an issue getting too close to the camera - I've done that plenty of times, it will just get a bit blurry but won't cause the camera to cut out. I would advise against running focus_owl.sh too long though - there could be issues there with too much blur.

To summarise:
1. check ribbon cable
2. leave software running with/without green detections and make sure it is updated using update_owl.sh.
2a. try running it with the default four lanes and see if it works. If it does but fails with 1 lane/detection zone then you'll know it's that.
3. Make sure it isn't running the focusing script.
4. are you using the original owl image downloaded form github or the latest Raspbian OS from Raspberry Pi? The latter will cause issues because it will want to run libcamera not picamera.

Kmrfarmsinc, 2023-12-15:
The ribbon for the camera was a little loose but it still happened after I fixed the ribbon.

I am going to give a picture below and I’m wondering if this could be the problem.
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

geezacoleman, 2023-12-16:
In that screenshot, you're working in the global environment for the OWL - we run the OWL software in a virtual environment, which is a way of keeping all the various other packages together. Helps with version control and managing conflicts. The issue is that anything outside the virtual environment `owl` is inaccessible to the owl software.

If you pip install things. always pip install them into the virtual environment `owl`, otherwise you'll run into issues.

To install into the virtual environment, you first need to activate it and then run the pip install commands.

```
workon owl
pip install --upgrade pip
pip install blessed
```

But I would just recommend running:

```
workon owl
bash update_owl.sh
```

This will download the latest OWL software, and install all the right dependencies into the right virtual environment too.

Closed 2023-03-06.

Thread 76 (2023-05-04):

green on green

manninb, 2023-05-04:
Hi All,
I have read some comments on the site about green on green. I'm just wondering if (for the technically incompetent)  you could give me a summary of where that is up to and the potential to update my existing unit to green on green? I understand the large time commitment in training such a system through  the bit of work I did with autoweed.

geezacoleman, 2023-05-10:
Hi Bill,

Overall I'd describe it as a beta version - it works on my desktop/Pi but it hasn't been field tested yet. Largely due to lack of datasets available to train models for it and fields to use it in. Hoping to change that this season.

To summarise, we developed the green-on-green capability using the Google Coral, which is a retrofit device for the Raspberry Pi to give it the power needed to run these large models. You just need to connect it via USB to the Pi, install a few things [as per the instructions here](https://github.com/geezacoleman/OpenWeedLocator/tree/main/models) and you're ready to run your own models. If you had a model in the correct format, you would drag it to the models directory and the system does the rest.

As you've identified, training the model is a big hurdle. But there are many high performing architectures (e.g. YOLOv5/v8/NAS) that are easy to get relatively high results from on smaller datasets that are good for prototypes.

So in short - very much possible to update your unit to green-on-green using the guide above, though it is still an early version. Any field testing you do would be greatly appreciated to iron out some issues. The challenge will be collecting data and training your own model for this purpose.

manninb, 2023-05-12:
Is the YOLO only for training ie, is it loaded on to the spray units or does it develop an algorithm that is used with the software you have written?

geezacoleman, 2023-05-12:
YOLO is an algorithm architecture (think of it like an unfurnished house) - if you give it weeds data to train on you can then load that trained/furnished algorithm onto the OWL to use to detect weeds. YOLOv5/v8 can be trained on Google Colab, an online tool for coding which gives you access to a high power graphics card for free.

The issues you're having with owl.py/greenonbrown.py are the result of trying to incorporate the outputs from the YOLO/other algorithms too (so my apologies for the hassle!).

manninb, 2023-06-14:
Hi
I'm interested in collecting images to see if I could get a green on green version going. In short I would be happy to put time in on this but I would need support in setting up the training software and incorporating the results into the OWL. This support I would think have to come from Syd Uni, so my question would be can you supply that?

geezacoleman, 2023-06-20:
Hi Bill, flick me an email and we can organise this further - would need to work out how many images/target weeds etc. but sounds like an interesting proposal

manninb, 2023-06-21:
Hi Guy,
My initial thought is could I use the OWL to collect the images, then  load them into some software and then go through and ID them? I don't know if this is practical,  storage  on the respberry may be an issue.  I think that is what the Auto Weed did when I was working with them. They were able to do a fairly fast turnaround  in terms of capturing images and Identifying them and training the model. In terms of how many  images are needed I couldn't say.  I would need  substantial help on the software side of things, but I could put in a fair chunk of time  capturing classifying images and testing the unit.  As a  research organisation Sydney uni may feel this is more a development job, not pure research and therefore not within the remit of the Uni.  Do we need to have a chat on the phone or teams etc?

I'm not sure which email for you is best to use.

Bill Manning Land Services - Advisory Services (Cropping)

North West Local Land Services

PO Box 546 |35-37 Abbott Street | Gunnedah NSW 2380

T: +61 2 6742 9210 | F:+61 2 6742 4022

M:  0428 607 731

***@***.******@***.***>

W: northwest.lls.nsw.gov.au<http://northwest.lls.nsw.gov.au/>

www.facebook.com/northwestlocallandservices<http://www.facebook.com/northwestlocallandservices>

________________________________
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

manninb, 2023-06-21:
Also I should have mentioned that I'm doing a talk at the weeds conference in Dubbo in August  on the work I have done with the OWL.  If you wish to have any input I'm more than happy to accommodate that.

Bill Manning Land Services - Advisory Services (Cropping)

North West Local Land Services

PO Box 546 |35-37 Abbott Street | Gunnedah NSW 2380

T: +61 2 6742 9210 | F:+61 2 6742 4022

M:  0428 607 731

***@***.******@***.***>

W: northwest.lls.nsw.gov.au<http://northwest.lls.nsw.gov.au/>

www.facebook.com/northwestlocallandservices<http://www.facebook.com/northwestlocallandservices>

________________________________
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

Closed 2024-01-03.

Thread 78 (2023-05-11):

Focusing camera (again)

manninb, 2023-05-11:
Sorry for the hassle but having not done this for a while, I'm again having an issue getting the camera view up.

I opened up the "terminal" from the main raspberry screen and did the following (see below). somehow I have come at it from the wrong wrong point but cant seem to find the correct one.

 I keeping getting this on the end of the command line  "/owl $"

pi@raspberrypi:~ $ cd ~/owl
pi@raspberrypi:~/owl $ workon owl
(owl) pi@raspberrypi:~/owl $ pip install -r requirements.txt
Looking in indexes: https://pypi.org/simple, https://www.piwheels.org/simple
Requirement already satisfied: numpy in /home/pi/.virtualenvs/owl/lib/python3.7/site-packages (from -r requirements.txt (line 3)) (1.21.0)
Requirement already satisfied: imutils in /home/pi/.virtualenvs/owl/lib/python3.7/site-packages (from -r requirements.txt (line 4)) (0.5.4)
Requirement already satisfied: gpiozero in /home/pi/.virtualenvs/owl/lib/python3.7/site-packages (from -r requirements.txt (line 5)) (1.6.2)
Requirement already satisfied: pandas in /home/pi/.virtualenvs/owl/lib/python3.7/site-packages (from -r requirements.txt (line 6)) (1.2.5)
Requirement already satisfied: glob2 in /home/pi/.virtualenvs/owl/lib/python3.7/site-packages (from -r requirements.txt (line 7)) (0.7)
Requirement already satisfied: RPi.GPIO in /home/pi/.virtualenvs/owl/lib/python3.7/site-packages (from -r requirements.txt (line 8)) (0.7.1)
Requirement already satisfied: picamera in /home/pi/.virtualenvs/owl/lib/python3.7/site-packages (from -r requirements.txt (line 9)) (1.13)
Requirement already satisfied: colorzero in /home/pi/.virtualenvs/owl/lib/python3.7/site-packages (from gpiozero->-r requirements.txt (line 5)) (2.0)
Requirement already satisfied: pytz>=2017.3 in /home/pi/.virtualenvs/owl/lib/python3.7/site-packages (from pandas->-r requirements.txt (line 6)) (2021.1)
Requirement already satisfied: python-dateutil>=2.7.3 in /home/pi/.virtualenvs/owl/lib/python3.7/site-packages (from pandas->-r requirements.txt (line 6)) (2.8.1)
Requirement already satisfied: six>=1.5 in /home/pi/.virtualenvs/owl/lib/python3.7/site-packages (from python-dateutil>=2.7.3->pandas->-r requirements.txt (line 6)) (1.16.0)
Requirement already satisfied: setuptools in /home/pi/.virtualenvs/owl/lib/python3.7/site-packages (from colorzero->gpiozero->-r requirements.txt (line 5)) (57.0.0)
WARNING: You are using pip version 21.1.2; however, version 23.1.2 is available.
You should consider upgrading via the '/home/pi/.virtualenvs/owl/bin/python -m pip install --upgrade pip' command.
(owl) pi@raspberrypi:~/owl $ ps -C owl.py
  PID TTY          TIME CMD
(owl) pi@raspberrypi:~/owl $

geezacoleman, 2023-05-11:
No worries - based on what you've copied in, it looks as though all the commands you have entered have worked, the final `ps -C owl.py` command will check if `owl.py` is running. If it returns just the headings 'PID TTY TIME CMD', then the program isn't running in the background. Is that what you mean? The focusing camera method is quite annoying and doesn't need to be so fiddly, so I've started a new issue #79 to resolve some of these hurdles. Ideally the code should just check everything itself.

In the meantime, if you want to run the software, try typing `./owl.py` or `python owl.py` to start the program. If you want to see the display make sure to add the `--show-display` flag too.

Hopefully this answers the question - feel free to post up more of the output if I have missed something and I can try debugging it for you.

manninb, 2023-05-11:
Hi. Still having no luck. I think there is something more fundamental I'm missing. I'll try another unit and see if I have any luck.

pi@raspberrypi:~ $ ./owl.py
bash: ./owl.py: No such file or directory
pi@raspberrypi:~ $ python owl.py
python: can't open file 'owl.py': [Errno 2] No such file or directory
pi@raspberrypi:~ $ ps -C owl.py
  PID TTY          TIME CMD
pi@raspberrypi:~ $ python owl.py
python: can't open file 'owl.py': [Errno 2] No such file or directory
pi@raspberrypi:~ $ ./owl.py
bash: ./owl.py: No such file or directory
pi@raspberrypi:~ $ ./owl.py

manninb, 2023-05-11:
tried on another unit and got a little further. (see below).

pi@raspberrypi:~ $ ps -C greenonbrown.py
  PID TTY          TIME CMD
  542 ?        00:12:42 greenonbrown.py
pi@raspberrypi:~ $ cd ~/owl
pi@raspberrypi:~/owl $ workon owl
(owl) pi@raspberrypi:~/owl $ pip install -r requirements.txt
Looking in indexes: https://pypi.org/simple, https://www.piwheels.org/simple
Requirement already satisfied: numpy in /home/pi/.virtualenvs/owl/lib/python3.7/site-packages (from -r requirements.txt (line 3)) (1.21.0)
Requirement already satisfied: imutils in /home/pi/.virtualenvs/owl/lib/python3.7/site-packages (from -r requirements.txt (line 4)) (0.5.4)
Requirement already satisfied: gpiozero in /home/pi/.virtualenvs/owl/lib/python3.7/site-packages (from -r requirements.txt (line 5)) (1.6.2)
Requirement already satisfied: pandas in /home/pi/.virtualenvs/owl/lib/python3.7/site-packages (from -r requirements.txt (line 6)) (1.2.5)
Requirement already satisfied: glob2 in /home/pi/.virtualenvs/owl/lib/python3.7/site-packages (from -r requirements.txt (line 7)) (0.7)
Requirement already satisfied: RPi.GPIO in /home/pi/.virtualenvs/owl/lib/python3.7/site-packages (from -r requirements.txt (line 8)) (0.7.1)
Requirement already satisfied: picamera in /home/pi/.virtualenvs/owl/lib/python3.7/site-packages (from -r requirements.txt (line 9)) (1.13)
Requirement already satisfied: colorzero in /home/pi/.virtualenvs/owl/lib/python3.7/site-packages (from gpiozero->-r requirements.txt (line 5)) (2.0)
Requirement already satisfied: pytz>=2017.3 in /home/pi/.virtualenvs/owl/lib/python3.7/site-packages (from pandas->-r requirements.txt (line 6)) (2021.1)
Requirement already satisfied: python-dateutil>=2.7.3 in /home/pi/.virtualenvs/owl/lib/python3.7/site-packages (from pandas->-r requirements.txt (line 6)) (2.8.1)
Requirement already satisfied: six>=1.5 in /home/pi/.virtualenvs/owl/lib/python3.7/site-packages (from python-dateutil>=2.7.3->pandas->-r requirements.txt (line 6)) (1.16.0)
Requirement already satisfied: setuptools in /home/pi/.virtualenvs/owl/lib/python3.7/site-packages (from colorzero->gpiozero->-r requirements.txt (line 5)) (57.0.0)
WARNING: You are using pip version 21.1.2; however, version 23.1.2 is available.
You should consider upgrading via the '/home/pi/.virtualenvs/owl/bin/python -m pip install --upgrade pip' command.
(owl) pi@raspberrypi:~/owl $ ps -C greenonbrown.py
  PID TTY          TIME CMD
  542 ?        00:22:25 greenonbrown.py
(owl) pi@raspberrypi:~/owl $ sudo kill 542
(owl) pi@raspberrypi:~/owl $ ~/owl/./owl.py --show-display
bash: /home/pi/owl/./owl.py: No such file or directory
(owl) pi@raspberrypi:~/owl $ sudo kill542
sudo: kill542: command not found
(owl) pi@raspberrypi:~/owl $ sudo kill 542
kill: (542): No such process
(owl) pi@raspberrypi:~/owl $

manninb, 2023-05-11:
I seemed to have turned this unit off and cant turn it back on

pi@raspberrypi:~ $ ps -C owl.py

PID TTY          TIME CMD
pi@raspberrypi:~ $ ./owl.py
bash: ./owl.py: No such file or directory
pi@raspberrypi:~ $

manninb, 2023-05-15:
when updating got an error message so I reflashed the card and then updated (see below) still got an error message managed to get the PID but still cant get camera up. Would it be possible to talk on the phone?, it might save you some time.
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
geezacoleman, 2023-05-27:
I've spent some time putting together/testing a few different scripts (#89 and #86 ) to somewhat automate both focusing and updating process. This should hopefully avoid a lot of the hassle.

To use both of these, you'll need to clone the latest repository. It assumes you have the old image flashed to the SD card.

In a new terminal window:

## Step 1 - Update the OWL
```
pi@raspberrypi: $ cd ~                  # makes sure you are in the home directory
pi@raspberrypi: $ mv owl owl-old            # renames owl directory to owl-old
pi@raspberrypi: $ git clone https://github.com/geezacoleman/OpenWeedLocator        #
pi@raspberrypi: $ workon owl                             # activates the owl environment (very important for running the update script)
(owl) pi@raspberrypi: $ cd owl                   # moves into the owl directory that you just downloaded
(owl) pi@raspberrypi:/owl $ bash update_owl.sh
```
Once you run the final `update_owl.sh` command it will:
1. update the whole system
2. download the new owl software again
3. install the requirements
4. change all the permissions of the relevant files automatically.

I've tested this a few times on my own system and it works fine. Just make sure you are in the `owl` virtual environment otherwise the packages won't be installed into the correct area.

During this process you will be asked to confirm a few things - just type `y` and press enter to continue. It will take about 5 - 10 mins to download and install everything given the age of the image. Do not interrupt it or it will brick the SD card (found this out the hard way accidentally).

Assuming it all goes to plan, you should have everything in the right place and with the right permissions after that has run.

## Step 2 - focus the OWL
I have also automated this process somewhat and added the value for blurriness/clarity to the display image. Once you have updated the OWL, you just need to run:

```
(owl) pi@raspberrypi:/owl $ bash focus_owl.sh
```

This will close any operating `greenonbrown.py` / `owl.py` instances and start the software with the --show-display and --focus flags. You should then be able to sort this out.

Here's an example of the new focusing layout. Blurry image has a low value while the clear image has a high value - moving the focusing ring on the lens to maximise this value. It's not perfect so double check it looks focused to you as well.
| Blurry Image | Clear Image |
|--------------|-------------|
|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 | 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 |

manninb, 2023-05-30:
That seems to be working - thanks very much, sorry for all the  back and forth.

geezacoleman, 2023-05-30:
Glad to hear it worked out for you! Thanks for helping improve this whole procedure and finding out some bugs along the way. I'll close this now as completed.

Closed 2023-05-30.

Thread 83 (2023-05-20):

Yikes! That's an expensive voltage regulator!

Minorplanets76, 2023-05-20:
The 5V regulator specified to power the Pi is as expensive as the Camera! I'm sure it's very good, but is it necessary?  Should other solutions be considered, e.g. POE for Ethernet connected modules or a big regulator powering multiple Pi's?  Maybe a custom HAT for OWL?

plains203, 2023-05-20:
That's the beauty of an open system. You can power it however you like.

geezacoleman, 2023-05-21:
The Pololu ones certainly [aren't cheap](https://www.pololu.com/product/2850), but given how noisy some of the incoming 12V might be it's nice to invest in a good quality power supply. They accept a wide range of input voltages and provide 5A output in case you need to run any other 5V things out of the OWL. There is also the 2.5A option which is a fair amount cheaper.

Lots of different 12V to 5V options out there that aren't pololu and are probably also quite good. If you're interested in having some of your own things built - check out this [driver board](https://github.com/geezacoleman/owl-driver-board) my brother built for the OWL. It incorporates the buck converter and the solid state relays into one board. Has PWM capabilities and is tolerant to noise/reverse polarity etc. Would recommend - having it built yourself can be cheap on a per unit basis.

Minorplanets76, 2023-05-21:
That's perfect. I'll build some of those. Already all over it. Good stuff.

Closed 2023-05-21.

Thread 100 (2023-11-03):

trigger delay

manninb, 2023-11-03:
Is there a way to shorten time between detection and nozzle activation as my unit seems to be triggering a bit late even at slow speeds.
I see a number there "delay" can that be shortened to less than zero?

geezacoleman, 2023-11-03:
Hi Bill,

It can't be shortened more than 0 unfortunately, so there's no easy software fix for this.

There are a few areas that can cause this though and can be fixed to improve performance:
1. Which software version are you using?
the original software is slower than the current version, so make sure it is updated.

2. check image resolution - should be set to 416 x 320.
High resolution will slow detection speed on the Pi

3. how far in front of the nozzles is the camera and/or is there a slight angle backwards? To fix this you can increase this distance or slightly angle the camera forwards. This is probably the simplest solution.

4. what sort of nozzles are you using?
I bought some cheap ones recently that are very slow to turn on and as a result will miss all weeds even at slow speeds.

I think improvements can be made in the efficiency of activating nozzles - it is quite a slow system currently. I'll add it to the todo list for the project.

manninb, 2023-11-06:
thanks for that I'll  check all the above. We are using goyen solenoids and nozzles, do you regard those as fast or slow?
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

geezacoleman, 2024-01-03:
Hi Bill, I think I've found a potentially major source of delay that is contributing to your error. I'm working on a proper solution to this that lets people retain the logging of all detections, but for your case I think it's best to remove it for the moment.

To fix this:
In `relay_control.py` go to [Lines 142 - 143](https://github.com/geezacoleman/OpenWeedLocator/blob/962e3fbf6a9e7a1be822a516436cb5b7f8a3e2e0/relay_control.py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) and delete them both.

````python
line = f"nozzle: {nozzle} | time: {timeStamp} | location {location} | delay: {delay} | duration: {duration}"
self.logger.log_line(line, verbose=False)
```

These are the two lines you want to remove. It will speed up the detection process a considerable amount. I tested it on my laptop and the time taken to run through each detection and activate it went from ~10ms to <0.01ms (effectively unrecordable on Python). So this will reduce the delay between the detection and actually activating the nozzle, hopefully going someway to solving your issue.

The only downside is the detection times and the information above will not be recorded. As mentioned above, I will be working on a longer term solution to this as a priority given how much of a performance increase it provides.

manninb, 2024-01-04:
Thanks again for your help, I’m away for a couple of weeks, but I’ll be back onto this soon.

Get Outlook for iOS<https://aka.ms/o0ukef>
________________________________
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

geezacoleman, 2024-11-14:
Hi Bill - the latest software version should be a lot better with this. Would recommend updating.

I'll still work on finding ways to decrease time between weed entering FOV and solenoid activating but for now I'll close this issue. Feel free to post any other comments/questions anytime though.

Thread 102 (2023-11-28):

PID Number not showing

Kmrfarmsinc, 2023-11-28:
Using the quick method, I am finding it easy to navigate through the steps until I get to the step where it asks you to find out and stop the program using the PID number. My second row doesn't show up. You list some solutions that may work for others but I am just not sure how to go about this. I followed the previous steps exactly and have erased and started over many times over. I have the same problem every time, would you be able to assist?

geezacoleman, 2023-11-29:
Thanks for persisting with the setup and trying it a few times. I have a few questions just to clarify what's happening a little more. Are you at the [Legacy Focusing](https://github.com/geezacoleman/OpenWeedLocator#legacy-focusing) step? If you successfully run the update owl step in [Step 4,](https://github.com/geezacoleman/OpenWeedLocator#legacy-focusing) you shouldn't need to do this. The focus_owl.sh file will do this all for you now. So this Legacy Focusing step isn't required.

But just in case - do you get errors if you run `owl.py` that may suggest the camera is running in the background?

Can you share the outputs/commands you are running in the lead up to this?

The second row will only likely show up if the program you specify (i.e. owl.py) is running - so if it isn't showing up, it could be due to owl.py being misspelled when you type or perhaps greenonbrown.py running instead, or otherwise it might not be running at all anyway so nothing to worry about.

Let me know how you go - happy to answer any more questions you might have.

geezacoleman, 2023-11-30:
Ok thanks for the update.

'blessed' is a Python library and it looks like it hasn't been installed into the ´owl´ virtual environment. Did you run

```
pi@raspberrypi:~/owl $ workon owl
(owl) pi@raspberrypi:~/owl $ pip install -r requirements.txt
```

You can also try just `pip install blessed`, just make sure you are in the `owl` virtual environment first by typing `workon owl`.

geezacoleman, 2023-11-30:
Great! Glad to hear you could get it running.

Yeh, we set it up for outdoors use in Australia, so all the settings are meant for those bright conditions, which means it's very dark inside. So good point on the focusing for indoor conditions - I might need to change it so you can specify indoor/outdoor when focusing or make the exposure mode auto.

To run it without the blurriness value (i.e. as normal), if you just want to see the feed, you can run:

`./owl.py --show-display --exp-mode 'auto'`

If you want to run ´focus_owl.sh´, you'll need to open it in a text editor and then edit the last line by adding the `--exp-mode 'auto'` flag too.

I'll update this in the repository for others to use too!

geezacoleman, 2023-12-16:
It seems this issue is resolved, so I'll close this one but feel free to add anything else that comes up or start a new issue if you come across any further issues.

Closed 2023-12-16.

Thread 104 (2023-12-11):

model testing

zerosnsa, 2023-12-11:
May I ask why this error occurs when my model passes the specified algorithm。
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

geezacoleman, 2023-12-11:
This error is most likely because pycoral isn't installed correctly, but can be because of a number of issues with the `GreenonGreen` class. Unfortunately the try/except block wasn't catching the error on model instantiation so it appears down here as 'referenced before assignment'.

I'd double check the pycoral installation first and also the presence of model files in the models directory. I'm working on some better error checking code here so the error is more visible too. Will let you know once that's done.

I worked through this [Pycoral guide](https://coral.ai/docs/accelerator/get-started/#requirements) and managed to get it working on my laptop, after experiencing the same issues without pycoral installed correctly.

Hope this helps! Let me know if there are further issues.

zerosnsa, 2023-12-12:
I am not using Google Coral USB, I am going to run the model directly on the Raspberry PI, is this OK? If it is shown in my python, this library is correctly installed

zerosnsa, 2023-12-12:
> 我现在添加了一些改进的错误检查逻辑。如果您想更新到最新版本，错误将更加清晰，因此希望修复也是如此。

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

geezacoleman, 2023-12-12:
You can run models directly on the Raspberry Pi but they will be quite slow without doing substantially more optimization. I wouldn't use a library like pycoral for that either. Unfortunately you can't just pip install pycoral - you need to follow the guide quite carefully for it to work. Even if it does appear in Python, it doesn't function correctly - it needs the Edge TPU runtime too.

If you update the OWL software to the latest version, the new error checking will provide you with the specific error.

Have a look at this repository for running models directly on the Pi 5: https://github.com/danigarci1/camera_tracking_rpi

zerosnsa, 2023-12-12:
So how should I run this project if I have jetson nano? What is the definition of slow time? What should my model staff look like if I use the jetson nano? The implementation seems to be more cost-effective than the jetson nano

geezacoleman, 2023-12-12:
If you use a Raspberry Pi 5 you could get higher framerates - it's hard to say exactly how fast it would be. But unoptimised object detectors on the Pi4 typically only get a 1-3 FPS. With the Google Coral you can get probably 15 - 20 FPS, or enough for reasonable operation speeds (of course depends on which model you choose - this is assuming a YOLOv8 N or similar). You can use pycoral without a Google Coral TPU connected, but you still need to install everything.

The project should work on the Jetson Nano fairly unchanged - but installation is more difficult. Setting up the Nano for model use requires some more work too, but again quite doable and it's something we've considered and would like to try. If you wanted to work on that and contribute it to the project that would be great!

zerosnsa, 2023-12-12:
So the jetson nano's frame rate is also indeterminate? May I ask whether the Connector-Panel Mount and Connector-Plug you use have the same function as the link below? They're supposed to function as a power switch, right? Is this link: https://detail.tmall.com/item.htm?id=744867676600

zerosnsa, 2023-12-12:
The main reason is that I can't buy these two connectors directly. If I buy them through international shopping and add the cost of Google Coral USB, the cost is much higher than that of jetson nano.

geezacoleman, 2023-12-12:
I'm being quite vague because it really depends on so many things:
* model size
* implementation
* training
* optimization

The Nano generally is more complicated to set up and unfortunately I couldn't offer any support. If you do get it working though it would be a really valuable contribution to the community! To help your decision, check out this [Reddit thread](https://www.reddit.com/r/computervision/comments/1161mab/should_i_get_a_google_coral_usb_accelerator_for/). It offers better advice than I could provide.

There are many guides out there for running YOLO and other object detectors on the Nano, so I think you'd be able to get help if you needed. You'll just need to get familiar with TensorRT and DeepStream.

> May I ask whether the Connector-Panel Mount and Connector-Plug you use have the same function as the link below? They're supposed to function as a power switch, right?

I unfortunately can't see what's at the link - do you have a screen shot?

zerosnsa, 2023-12-12:
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
Because I have not seen the specific function of the connector you used, I can't know whether the one in my country has the same function, please help me to have a look

zerosnsa, 2023-12-12:
I will try to run this project on jetson nano when I have time. Just because I have an idle jetson nano, I haven't run all the steps on Raspberry PI yet, so I can't directly try it on Raspberry PI. I want to start it when I understand the whole project

zerosnsa, 2023-12-12:
I will try to run this project on jetson nano when I have time. Just because I still have an idle jetson nano, I haven't run all the steps on Raspberry PI yet, so I can't directly try it on jetson nano. I want to start when I know the whole project

geezacoleman, 2023-12-12:
That connector looks quite good! You just need +/- 12V in and then a wire for every solenoid you want to run. So it would be 6 in the default OWL configuration. The one in the photo looks like it would work. If you want to use the 3D printed enclosure, just check the diameter and clearance of the panel mount part - ours is 30mm diameter.

Let me know how the Nano goes - will be great to see it run on that!

zerosnsa, 2023-12-12:
How many weeds does your model detect, and is the implementation affected by the size of the data set? Can models be shared? To simply run the model through Raspberry PI, do I just need to modify greenongreen.py, or do I also need to modify owl.py? At present, the layout of the model is a little confusing. I also hope that I can realize this on the jetson nano, which is more cost-effective for me

zerosnsa, 2023-12-12:
Hello, I still have a doubt, that is, the model reasoning is in Google Coral, then I use the Raspberry PI zero 2w and Raspberry PI 3 such as, the frame rate is not any difference?

geezacoleman, 2024-01-03:
> How many weeds does your model detect, and is the implementation affected by the size of the data set? Can models be shared?

The default detection is simply 'green' detection, so it will detect all sorts of weeds, plants and green objects. We don't currently provide any trained models for the 'green on green' or gog use. As mentioned in the response to #113, you just need to modify `owl.py`.

> the model reasoning is in Google Coral, then I use the Raspberry PI zero 2w and Raspberry PI 3 such as, the frame rate is not any difference?

I don't think that will work - the Pi3 and others are still slower and don't have USB3.0 support. [Check out this article](https://helloworld.co.in/article/google-coral-usb-accelerator-performance-raspberry-pi-3b-3a-4b) for more details.

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
[source](https://helloworld.co.in/article/google-coral-usb-accelerator-performance-raspberry-pi-3b-3a-4b)

zerosnsa, 2024-01-04:
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
Why does this error occur when I install Coral USB accelerator?

geezacoleman, 2024-01-04:
These installation instructions are taken from the official ones from Google/PyCoral. I double checked and they are the same, so unfortunately it is more of an issue for them or your own setup than the OWL.

But to start with I would double check you have internet access on the Pi and can access Google products/cloud services. The full set of instructions are here: https://coral.ai/docs/accelerator/get-started/#1-install-the-edge-tpu-runtime.

zerosnsa, 2024-01-04:
I use your system image, and according to the official steps to use, but I do not know where the problem occurred, there will be errors! You can ping Google on the Internet

zerosnsa, 2024-01-04:
I perform curl https://packages.cloud.google.com/apt/doc/apt-key.gpg | sudo apt - key add - when would be a mistake, according to can not find this, what is the version do you use

zerosnsa, 2024-01-04:
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
What I keep getting is this error, and I can't find libedgetpu1-std and libedgetpu1-max

geezacoleman, 2024-01-04:
The primary issue isn't that you can't find those two packages, it's that you cannot connect to packages.cloud.google.com where they are located. It's some type of permissions error where you're blocked from access.

Have a read through this forum - unfortunately I can't provide more help on this, so I would recommend researching the specific issue and using various forums and reporting back your solution.
https://www.googlecloudcommunity.com/gc/General-Misc-Q-A/How-do-I-unblock-my-server-s-IP/m-p/649978

zerosnsa, 2024-01-05:
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
I downloaded the libedgetpu1-std package offline and installed it. Then, if I used sudo apt-get install python3-pycoral, I could not find the pycoral package. I used pip3 to download it. However, in the owl environment, python has shown pycoral package, but when I execute the code, the following error occurs, indicating that there is no module, may I ask what is the problem?
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

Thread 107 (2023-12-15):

Power supply to RPi

MerbeinRobotics, 2023-12-15:
Hello.
I recently started field testing my OWL unit but have noticed it seems to "freeze" after about 90 seconds an then appears to
 restart itself and go for another 90 seconds or so (I hear the beep beep start up sound with out switching the unit off and on) .  I suspect I have a power supply issue to the Raspberry Pi as the red power light seems to intermitantly turn off and on although the OWL still works even when the red power light is off.  I'm powering the RPi from a 12v battery and a 12v to 5v converter.

So I'm wondering if anyone else has experienced a similar problem and may have a fix?

Thanks,

Stephen

MerbeinRobotics, 2023-12-15:
Thanks Guy,

Yes I'll try powering the pi via the GPIO pins from the voltage regulator.  See photo of the setup below.  When I was building the system I had trouble powering the pi, the red light would not stay illuminated so I tried several regulators but changing the USB converter seemed to help the most.

I've included the photo of the pump set up just in case anyone might be interested in the plumbing as well.  Notice I had to put black tape over some of the green frame of the robot?  I had built the robot frame and painted it green before the OWL project came along.  When I first tested the OWL it was detecting the green paint of the robot, just as it should have!

I'll keep you updated.

PS Ever considered a PCB for the project?

Thanks,

KInd Regards,

Stephen

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

MerbeinRobotics, 2023-12-16:
Just a quick update.  After bit more investigating I discovered the output pins on the voltage regulator I was using where loose and not soldered to the regulator's PCB properly.  After re-soldering it ran for a least 10 minutes so I think my problem is sorted.  Although the red power light on the RPi wasn't on.  Anyway I'll some more testing and see how it goes.

Thanks and Kind Regards,

Stephen

geezacoleman, 2023-12-16:
Thanks for the update Stephen - looks like you've found the issue. I've also had the painful problem of a broken wire inside the insulation before, which took about  a week to discover! They're some great pics of the rover, so feel free to share them on the Community Builds page too.

I'll close this issue for now but feel free to reopen if you need.

Closed 2023-12-16.

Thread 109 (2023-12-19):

[ERROR] Unknown algorithm gog, using default...

gnaegit, 2023-12-19:
I followed the instructions [here](https://github.com/geezacoleman/OpenWeedLocator/blob/main/models/README.md) to test the GoG algorithm.
To install pycoral i followed the instructions [here](https://coral.ai/software/#debian-packages):
`python3 -m pip install --extra-index-url https://google-coral.github.io/py-repo/ pycoral~=2.0`
When running
`(owl) pi@raspberrypi:~/owl $ python owl.py --show-display --algorithm gog`
I got the following output
```
[INFO] Setting up nozzles...
[INFO] Nozzle setup complete. Initiating camera...
[INFO] Camera setup complete. Settings:
Resolution: (416, 320)
Framerate: 40
Exposure Mode: beach
AutoWhiteBalance: auto
Exposure Compensation: -4
Sensor Mode: 0
 Nozzle 1    Nozzle 2    Nozzle 3    Nozzle 4
                                              [ERROR] Unknown algorithm gog, using default...
[INFO] Using ssd_mobilenet_v2_coco_quant_postprocess_edgetpu model...

[ALGORITHM ERROR] Error while starting algorithm: gog.
Error message: Failed to load delegate from libedgetpu.so.1
```
stating that the algorithm gog is unknown.

Is this issue known?

geezacoleman, 2023-12-19:
The error `[ERROR] Unknown algorithm gog, using default...` is a quirk of the way I've tried to better capture errors. It tried to look for a model file called `gog` but can't find it, so it then defaults to the first one in the directory. That isn't likely to be the error here, because it then loads `ssd_mobilenet_v2_coco_quant_postprocess_edgetpu` - is this the model you want to use?

`Failed to load delegate from libedgetpu.so.1` is likely causing the issues. I would recommend reading through this [tensorflow issue](https://github.com/tensorflow/tensorflow/issues/32743) and trying some of their solutions:
1. make sure the Google Coral is connected
2. restart the device after installing
3. changes to [udev rules](https://github.com/tensorflow/tensorflow/issues/32743#issuecomment-570811813) that may or may not have happened.

Let me know how this goes for you. I'll fix that `gog` error though.

gnaegit, 2023-12-19:
Thanks for the fast response and the guidance.
Unplugging and replugging the Google Coral did the job. I'm pretty sure the Google Coral was plugged in before, as the LED was turned on.

gnaegit, 2023-12-20:
We are from a Swiss university of applied sciences. We don't have any specific ideas yet and would like to use the system in research and teaching.

geezacoleman, 2023-12-20:
That's great to hear, let me know if there's anything I can do to help. There should be a lot more frequent updates and improvements next year.

Closed 2023-12-29.

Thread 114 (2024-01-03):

logging causing substantial delay

geezacoleman, 2024-01-03:
Digging through the solenoid actuation code to try and improve speed, found that Line 143 of `relay_control.py` is causing a substantial delay.

Current line:
```python
self.logger.log_line(line, verbose=False)
```

The way individual weeds and updates are logged currently is through the custom `logger.py`. It's a very inefficient way of doing it. Testing this section of code in `owl.py` it took on average ~10 ms to detect one weed, and over 400ms if there were at least 10 - 20 detections, effectively bogging down the code and reducing spot spraying performance.

```python
# loop over the ID/weed centres from contours
startTime = time.time()
for ID, centre in enumerate(weedCentres):
    # if they are in activation region the spray them
    if centre[1] > self.yAct:
        sprayTime = time.time()
        for i in range(self.nozzleNum):
            # determine which lane needs to be activated
            if int(self.laneCoords[i]) <= centre[0] < int(self.laneCoords[i] + self.laneWidth):
                # log a spray job with the controller using the nozzle, delay, timestamp and spray duration
                # if GPS is used/speed control, delay can be updated automatically based on forward speed
                self.controller.receive(nozzle=i, delay=delay, timeStamp=sprayTime, duration=sprayDur)

endTime = time.time()
elapsedTimeMs = (endTime - startTime) * 1000
self.processingTimes.append(elapsedTimeMs)

if len(self.processingTimes) > 10:
    self.processingTimes.pop(0)  # remove the oldest number
rollingAverage = sum(self.processingTimes) / len(self.processingTimes)
```

### Workaround
Deleting this line entirely from `relay_control.py` solves the problem but it means individual detections won't be logged.

### Longer term solution
Replace all logging with the python logging module. Testing this method increased processing time above deleting the line entirely but even with many detections processing time remained below 1ms.

Issue first raised in Issue #100

geezacoleman, 2024-11-08:
New logging system added in #155 . Detections still to be logged - will add in due course.

Closed 2024-11-08.

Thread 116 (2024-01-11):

Field Start-Up

Kmrfarmsinc, 2024-01-11:
Hello again, I am at the very last step until I take it out in the field for testing. The only problem that I think will be an issue is the program running as soon as I put power to it. When I want to run the owl program on my desktop, I have to execute that in the terminal. How would you adjust it so it starts working right away when I get in the field?

I looked through the previous issues and didn’t seem like it was something talked about.

geezacoleman, 2024-01-12:
Great that it's almost ready for field testing.

The OWL software should start automatically on powerup. Do you hear two beeps when you power it on without anything attached?

All the hassle with stopping programs just to start them again is because of owl.py starting when the Raspberry Pi boots. If it's set up correctly you should be able to turn it on/off and hear the beeps without using the terminal.

If that doesn't happen, it might be because a couple of files aren't set to executable. You can run these lines from terminal and it should fix it:

```
(owl) pi@raspberrypi:~/owl $ chmod a+x owl.py
(owl) pi@raspberrypi:~/owl $ chmod a+x owl_boot.sh
```

The only changes you'll need to make to owl.py file are if you have changed default settings through the command line. For example if you used --exp-compenstion 0, that won't be saved. So you need to go into the code and change the default.

geezacoleman, 2024-02-08:
How did you go with this @Kmrfarmsinc? Let me know if you run into any other issues and I can try to help.

Kmrfarmsinc, 2024-03-14:
I have been off and on trying to get it going but I still am having trouble with the auto start. I have a buzzer and when I first turn on the raspberry pi, I only get one beep. I’m not sure what this means. I don’t know if the program is just supposed to be running in the background for the auto start or if you are supposed to see the feed like normal. Everything else seems to be working well. I have a quality video, and I see the nozzles that are wanting to spray. If you have any suggestions on what the problems may be, let me know when you are able to. Thanks

Kmrfarmsinc, 2024-03-15:
I tried the initial two lines that you suggested and that didn’t seem to work. I looked in the detailed startup and tried to use those 5 lines to have that work, and that didn’t work as well. Just wanted to give more info on what I did. (Feed means video feed, show we always see that when it’s working or could it just be in the background?)

Kmrfarmsinc, 2024-03-16:
So I just got it to work with the two beeps at startup and the LED light showing me when it is spraying. The picture is clear and everything seems to be working perfectly. The program does seem to be working in the background off start-up because of the LED flashing. I did buy your relay board because you made a really good board (probably show advertise that a lot more in the instruction page instead of just the forums), and it was easy to get everything set up. When I use it this season, I will be sure to send videos of the program running back here for people to see the benefits from it, thanks again.

geezacoleman, 2024-03-19:
That's great, glad you could get it working. If everything is set up correctly, it will just work in the background after start up with no video feed or any visible signs, besides the LED flashes/solenoid clicks you might hear. Two beeps after startup is essential - if you only hear one or none, then it probably isn't working correctly.

Just for the benefit of others reading this, what do you think the issue was and how did you fix it?

Thanks for purchasing those OWL driver boards too, they should make it a bit easier. How have you found them so far?

Kmrfarmsinc, 2024-03-28:
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

As far as the problems with setting up the program, that was all user error being the first time I’ve tried something like this. The hardware was a bit tricky but if we bought all of your products you suggested it would have worked fine. We just miss wired the onto the prongs the first time.

We just got the new board, and haven’t tried it yet. Does the wire schematic that I drew look correct. It says 5v on the PC board. I’m assuming that comes from the PI computer and we use 12v to power up the solenoids? The jumper I have circled stays non-jumped? I just could find any instructions on this and didn’t want to wire it wrong.

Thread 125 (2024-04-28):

~/owl/./owl.py --show-display not working on rapi 5 or rpi 3b

pedro26538, 2024-04-28:
this log is with rpi 5 with rpi cam

(owl) raspi@raspberrypi:~ $ ~/owl/./owl.py --show-display
[INFO] Setting up nozzles...
[INFO] Nozzle setup complete. Initiating camera...
Traceback (most recent call last):
  File "/home/raspi/owl/./owl.py", line 546, in <module>
    owl = Owl(input_file_or_directory=args.input,
          ^^^^^^^^^^^^^^^^^^^^^^^^^^^^^^^^^^^^^^^
  File "/home/raspi/owl/./owl.py", line 158, in __init__
    from picamera import PiCameraMMALError
  File "/home/raspi/.virtualenvs/owl/lib/python3.11/site-packages/picamera/__init__.py", line 72, in <module>
    from picamera.exc import (
  File "/home/raspi/.virtualenvs/owl/lib/python3.11/site-packages/picamera/exc.py", line 41, in <module>
    import picamera.mmal as mmal
  File "/home/raspi/.virtualenvs/owl/lib/python3.11/site-packages/picamera/mmal.py", line 49, in <module>
    _lib = ct.CDLL('libmmal.so')
           ^^^^^^^^^^^^^^^^^^^^^
  File "/usr/lib/python3.11/ctypes/__init__.py", line 376, in __init__
    self._handle = _dlopen(self._name, mode)
                   ^^^^^^^^^^^^^^^^^^^^^^^^^
OSError: libmmal.so: cannot open shared object file: No such file or directory

geezacoleman, 2024-04-28:
Which version of Raspian are you running and what was the install method? The error you're receiving is likely because picamera isn't installed, usually because the OS is Raspbian Bookworm or a recent version, which doesn't support picamera.

This has been fixed over on the [Picamera2](https://github.com/geezacoleman/OpenWeedLocator/tree/picamera2) branch and should be merging it to the main branch this week. Feel free to try out this branch, just make sure to replace the `git clone https://github.com/geezacoleman/OpenWeedLocator` with `git clone -b picamera2 https://github.com/geezacoleman/OpenWeedLocator/tree/picamera2 owl`, otherwise you'll end up with the code from the main branch which won't help.

Closed 2024-10-16.

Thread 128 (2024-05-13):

Compact OWL model defects / printability issues

MisterHW, 2024-05-13:
Compact OWL as of https://github.com/geezacoleman/OpenWeedLocator/tree/68f2ee177ff4bf59b490357e216150cbcec619c8/3D%20Models/Compact%20OWL has a few issues affecting printability and the function of the o-ring face seals.

### tray.stl

The bottom of the model is not flat, leading to most of the area not being exactly on the print bed

### main-body.stl

The profile presents as a multi-part stl. Older slicers don't fuse everything into a single object, which causes the rails to be pinted separately, and they may or may not be bonded to the profile.

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

failed test print section:

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

### frontplate.stl

The o-ring groove does not follow the main body cross-section.

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

## partial recreation in FreeCAD

FreeCAD may not be the best choice for a redo, but I've recreated the extrusion profile and a blind end cap (which can then be cloned and specialized). This ought to give a glimpse into the workflow and level of hassle when using this particular CAD program.

[OWL Compact FreeCAD example (plus 3mf, step).zip](https://github.com/geezacoleman/OpenWeedLocator/files/15298824/OWL.Compact.FreeCAD.example.plus.3mf.step.zip)

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

Here's another view of the end cap with o-ring groove. It's not dimensioned absolutely correctly.

Note: 3D printed parts can be expected to exhibit some level of creep, especially since there is a heat source inside. Therefore, it's probably best to use Shore 15 EPDM foam o-ring material and a conservative amount of compression. Since the flat areas around the M5 holes butt up against ```main body```, it's the depth of the groove w.r.t. this plane.

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

geezacoleman, 2024-07-03:
Thanks for finding these @MisterHW ! Not sure how those rails separated in the design, but they should be fixed now in #137. I have also added a blank backplate and raised up the receptacle/gland to avoid contact with the USB/ethernet ports on the Raspberry Pi when fitted.

MisterHW, 2024-07-04:
Thanks for addressing it. In a future PR, a few other tasks can be addressed:
- completed re-creation of the Compact OWL design in FreeCAD
- .step export of components and a full model
- a visual index markdown showing all the models with explicit instructions which files to download and print

Closed 2024-07-04.

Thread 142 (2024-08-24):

Green on green

bassyboi, 2024-08-24:
Trying to figure out how to install coral on raspberrypi 4 using python 3.12!!! I tried back dating the python but run into trying to troubleshoot why the code not running with everything required and paths set up correctly!!! Any suggestions?? I have a data set here that seems to work well in pasture on laptop on my own script over a video!!  Any suggestions

geezacoleman, 2024-08-26:
Thanks for giving this a go! As you've probably found out unfortunately Google has not updated the PyCoral library for the Coral in some time. There are a few options you can try that have been developed by the community. What are your specific errors? Can you screenshot/copy paste them here? Which dataset are you using or is it one you've developed yourself?

There's a great video explaining the set up process by the [YouTuber Jung](https://www.youtube.com/watch?v=HMeDLSflCA0). This thread on the issue (https://github.com/google-coral/pycoral/issues/137) also provides some options to run it with post 3.9 versions of Python. The issue with backdating python is you'll run into compatibility issues with picamera2 I think and other packages.

I explain a bit more about the situation/plans in #141. When I set up GoG support for the OWL with the Coral and PyCoral I assumed there would be ongoing support for the hardware/software. Unfortunately it seems that isn't the case and the community is moving toward other options like the Hailo AI Kit. The Raspberry Pi 5 can run small models at moderate FPS, but having the additional hardware like the Hailo chip using the PCIe connection greatly improves speed. I'd recommend upgrading to a Pi 5 if you want to run GoG models in the future - it will be much better supported/faster.

bassyboi, 2024-08-26:
I have tried back dating the raspberry pi!!! I kinda wrote a script that sets up setting up python 3.9 in its own environment to run the coral (env-coral) in and use the rest of owl to run in the owl in (owl) I got it running once thought I got it right had camera up detecting weeds in my lawn thought I solved it then reset raspberry pi and kept saying I have to install open cv and a few and can’t get it to run again

bassyboi, 2024-08-26:
Also yes I made a custom data set

geezacoleman, 2024-08-30:
This is really neat! Thank you for sharing the process and my apologies for not responding sooner or for being much help! It looks like you've got it sorted far better than I could have in any case. Your dataset sounds great - I have found that grouping very different weeds together may negatively impact model training, because of the diversity in appearance that the weeds present. Depends on the context and crop/background however. I have also found the opposite, where too many classes of very similar classes can result in poorer training, so I think there is a middle ground. Do you have some examples?

GoG will be a focus for me in the next 6 months starting from late September, so expect there to be a lot more support for it and updates. The idea is to update the [openweedlocator-tools](https://github.com/geezacoleman/openweedlocator-tools) package and use that as the base for the main OWL repository. That way functions can be run independently and interact better with a GUI too.

Thanks again for sharing!

bassyboi, 2024-08-30:
yeah i trained and retrained the model with the likes clover mash mellow weed  and that for a trial... just with weeds and that around the house in my area but had like 1500 photos and i hated sitting there trying to put a box over every weed haha

Closed 2024-08-28.

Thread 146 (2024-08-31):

green on green lidar or height adjustment

bassyboi, 2024-08-31:
keeping boom at correct height in gog applications to allow correct distant for boom height and camera field of view...

geezacoleman, 2024-09-01:
Yes, this is definitely a challenge. My feeling is lidar might be overkill for it? Perhaps a ToF sensor or ultrasonic sensor are the easiest ways to do it. I think commercial booms use ultrasonic sensors spaced out over the length for this.

bassyboi, 2024-09-01:
ill checkout how the new jd ploughs do it have used one that is called accudepth i will investigate

bassyboi, 2024-09-01:
TF-luna Lidar Sensor 0.2m-8m maybe something like this +- 6cm accuracy

i know holley now make a similar sensor for there new fuel tank gauge that is lidar  the new jd ploughs do have them and they work great

geezacoleman, 2024-09-18:
This is pretty neat and quite cost effective too. How would you control boom height with this? Alternatively if you know boom height at different locations, you can better map detections to actual location, rather than the basic way it works currently.

bassyboi, 2024-09-18:
I seen something even neater then this with object detection and depth cameras might be expensive!!!

I’d just set a actuator up or solenoids up and down 50 mm+-  threshold but my still need to think more about this

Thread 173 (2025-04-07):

Enhancement: Migrate OpenWeedLocator to a Yocto-Based Linux Distribution for Improved Performance, Customization, and Future Scalability

bassyboi, 2025-04-07:
Summary
This issue proposes replacing the current Raspberry Pi OS (Raspbian) with a custom Linux image built using the Yocto Project. The goal is to create a leaner, faster, and more maintainable OS tailored specifically to the needs of OpenWeedLocator (OWL), while also paving the way for future deployment on custom hardware boards. Deep research shows that Yocto offers significant advantages in system footprint, boot time, performance, customization, OTA update support, CI/CD integration, and long-term maintainability.

⸻

Background
OWL currently runs on Raspberry Pi hardware using Raspberry Pi OS—a Debian-based distribution designed for general-purpose use. Although this OS provides a quick way to get started, it includes many packages and services that are unnecessary for our specific application, resulting in:
	•	A larger storage footprint,
	•	Slower and less deterministic boot times,
	•	Reduced performance for core image processing tasks, and
	•	A system that is less adaptable to future custom hardware designs.

⸻

Advantages of Migrating to Yocto
	1.	Smaller System Footprint
	•	Yocto: Builds a minimal image including only necessary components, resulting in dramatically reduced storage requirements.
	•	Benefit: Reduced SD card wear, lower memory usage, and a leaner runtime environment.
	2.	Faster & More Deterministic Boot Time
	•	Yocto: Eliminates unnecessary services and optimizes the initialization process, achieving boot times in a few seconds.
	•	Benefit: Quick recovery and responsiveness in field deployments.
	3.	Improved Performance & Optimization
	•	Yocto: Custom builds allow compile-time optimizations tailored to our hardware (e.g., Raspberry Pi 4’s Cortex-A72).
	•	Benefit: More resources available for OWL’s core functions like real-time image processing.
	4.	Greater Customization & Modularity
	•	Yocto: Provides a modular build system (via meta-layers and recipes) to include only required drivers, libraries, and features.
	•	Benefit: Reduced attack surface, easier troubleshooting, and a system that exactly fits OWL’s requirements.
	5.	Easier Support for Custom Hardware Boards
	•	Yocto: Offers extensive board support packages (BSP layers) and the ability to support a wide range of ARM-based or custom boards.
	•	Benefit: Future-proofs the project by enabling seamless migration from Raspberry Pi hardware to custom embedded solutions.
	6.	Better Support for Secure, Atomic OTA Updates
	•	Yocto: Natively integrates with OTA frameworks (such as RAUC, SWUpdate, or Mender) to enable atomic, fail-safe updates.
	•	Benefit: Ensures robust remote update mechanisms with rollback capabilities, reducing downtime and the risk of bricked devices.
	7.	Improved CI/CD Integration
	•	Yocto: The entire build process is scripted and reproducible, making it easier to integrate into automated CI/CD pipelines.
	•	Benefit: Streamlined testing and deployment, ensuring consistent and reliable image builds across releases.
	8.	Long-Term Maintainability & Scalability
	•	Yocto: Offers long-term support (LTS) releases and a controlled upgrade path, ensuring that security patches and updates can be applied smoothly.
	•	Benefit: A stable software foundation that scales from prototypes to mass-deployed devices.

bassyboi, 2025-04-07:
Comparison Table
Aspect
Raspberry Pi OS
Yocto-Based Custom OS
System Footprint
Large image with many unnecessary packages
Minimal image with only required components
Boot Time
Slower boot (tens of seconds), many background services
Fast, deterministic boot (a few seconds) thanks to streamlined initialization
Performance Optimization
General-purpose performance; not fully optimized for OWL’s specific needs
Custom-tailored optimizations for CPU and resource efficiency
Customization & Modularity
Limited customization; removal of packages can risk dependency issues
Fully modular design with meta-layers and recipes for precise configuration
Support for Custom Hardware
Tied closely to Raspberry Pi hardware (Broadcom SoC)
Broad hardware support via BSP layers; facilitates migration to custom boards
OTA Update Mechanism
Uses non-atomic package updates; risk of partial failures
Supports atomic, fail-safe OTA updates with integrated tools like RAUC, Mender, etc.
CI/CD Integration
Manual image customization and testing; prone to environment drift
Reproducible builds integrated into automated pipelines
Maintainability & Scalability
Updates and long-term support tied to Debian’s release cycle
LTS releases and a controlled update process ideal for production-scale depl

bassyboi, 2025-04-07:
Implementation Plan
	•	Setup Yocto Build Environment: Establish a development environment for Yocto targeting Raspberry Pi 4 initially.
	•	Develop Custom Meta-Layers: Create and/or integrate existing meta-layers for OWL’s required drivers, libraries, and application binaries.
	•	Image Customization: Configure the build to strip unnecessary components, focusing on a minimal footprint.
	•	OTA Update Integration: Evaluate and integrate an OTA update framework (e.g., RAUC or Mender) to enable atomic updates.
	•	CI/CD Pipeline Integration: Develop scripts and configurations for automated builds and testing to ensure reproducibility.
	•	Testing & Validation: Thoroughly test the new image on current hardware and simulate deployment scenarios for future custom boards.
	•	Documentation & Rollout: Document the build process and provide migration guidelines for future hardware targets.

⸻

Conclusion
Migrating to a Yocto-based custom Linux distribution offers significant long-term benefits for OpenWeedLocator. The enhanced performance, rapid boot times, lean system design, and robust update mechanisms will not only improve current operations but also prepare the project for future scalability—including deployment on custom hardware boards. This change is a strategic investment towards an industrial-grade, maintainable, and future-proof platform.

I invite discussion on this proposal and feedback on the implementation roadmap.

Closed 2025-04-07.

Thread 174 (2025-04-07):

Create “canbus” Branch for Basic Section ON/OFF via CAN with Node‑RED (Master)

bassyboi, 2025-04-07:
Description:

We propose creating a dedicated “canbus” branch in our repository to consolidate all work related to CAN bus integration. This branch will include our initial implementation of a basic Node‑RED master running on a Raspberry Pi that uses GPIO inputs to send CAN commands to control sections (meters) by turning them on or off. Error messaging and advanced handling will be addressed in future iterations.

Goals for the “canbus” Branch:
	•	Basic Functionality:
	•	Implement a Node‑RED flow for the master Raspberry Pi that uses GPIO input nodes (rpi gpio in) to detect button presses.
	•	Convert GPIO events to JSON payloads indicating the specific section (meter) and desired command (1 for ON, 0 for OFF).
	•	Build a CAN message (for example, using CAN ID 0x300 with a two‑byte payload) and transmit it via a SocketCAN Out node.
	•	Demonstrate that sections can be individually turned on or off, or that broadcast commands (e.g., ALL ON/OFF) work as expected.
	•	System Integration:
	•	The basic CAN messages from the master will be used to control slave nodes (each representing a one‑meter section) which will eventually integrate with Open AgiGPS.
	•	The focus of this branch is on the master’s ability to send correct commands via CAN; error messaging, logging, and advanced handling will be implemented later.

Motivation:
	•	Modular Development:
Creating the “canbus” branch allows us to keep our CAN bus integration separate from our main codebase while we work on and refine this feature.
	•	Basic Control Implementation:
Initially, we need only a straightforward mechanism that uses physical buttons (via GPIO) to trigger CAN messages to turn sections on or off.
	•	Future Enhancements:
Once the core functionality is stable, we can integrate enhanced error messaging, robust logging, and advanced command processing.

Acceptance Criteria:
	•	A new branch named “canbus” exists containing:
	•	A Node‑RED flow configured on the master Raspberry Pi that reads GPIO inputs.
	•	Logic to convert inputs into JSON payloads for the CAN bus.
	•	A function to construct and send a CAN message (using CAN ID 0x300) via SocketCAN.
	•	Functionality that correctly turns sections on or off when corresponding hardware buttons are actuated.
	•	Documentation is updated with instructions for setting up Node‑RED on the Raspberry Pi and testing the basic GPIO-to-CAN integration.
	•	Future tasks for error handling and advanced features are identified and documented for later development.

Additional Context:
	•	This is a basic implementation aimed at establishing reliable ON/OFF control. Error handling and more detailed logging messages will be developed in a subsequent iteration.
	•	We currently use Node‑RED on the master Raspberry Pi as our control hub. Slave nodes (one‑meter sections) will receive the CAN commands and interface with Open AgiGPS in later branches.
	•	Any related issues or pull requests should reference this branch for continuity.

bassyboi, 2025-04-08:
https://github.com/bassyboi/Owl-can-master-/tree/main

Still got to write read me.md sort of a draft read me also need to make the install better with the right libraries and that for it to work! Will update

EchelonMirror, 2025-04-28:
You thinking of running this virtually or having literal CAN hardware on the units? Alternative consideration for powering units being PoE/PoE+ and having all comms over a higher throughout bus.

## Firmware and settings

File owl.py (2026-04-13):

#!/usr/bin/env python
import os
import sys

import logging
import argparse
import time
import threading
from collections import deque

try:
    import serial
except ImportError:
    serial = None
from datetime import datetime
from multiprocessing import Process, Value
from pathlib import Path

from utils.error_manager import MJPEGStreamError


def get_python_env():
    """Get current Python environment status"""
    venv = os.environ.get('VIRTUAL_ENV')
    if venv:
        return f"Virtual environment: {venv}"
    return "No virtual environment active (using system Python)"


def setup_basic_logger():
    """Simple startup logger that uses the same file as LogManager"""
    log_dir = Path(os.getcwd()) / 'logs'
    log_dir.mkdir(exist_ok=True)

    file_handler = logging.FileHandler(log_dir / 'owl.jsonl')
    file_handler.setFormatter(logging.Formatter('%(asctime)s - %(levelname)s - %(message)s'))
    console_handler = logging.StreamHandler(sys.stdout)
    console_handler.setFormatter(logging.Formatter('%(asctime)s - %(levelname)s - %(message)s'))

    root_logger = logging.getLogger()
    root_logger.setLevel(logging.INFO)
    root_logger.addHandler(file_handler)
    root_logger.addHandler(console_handler)

    return logging.getLogger('owl_startup')


logger = setup_basic_logger()
logger.info("Starting OWL - checking imports...")

try:
    import utils.error_manager as errors
except ImportError:
    logger.critical("Cannot import from utils package! Not in correct directory.")
    logger.critical(f"Current working directory: {os.getcwd()}")
    print("\nERROR: Cannot import from utils package!")
    print("This usually means you are not in the correct directory.")
    print("\nTo fix:")
    print("1. Ensure owl environment is active: workon owl")
    print("2. Navigate to owl directory:        cd /home/owl/owl")
    sys.exit(1)

try:
    import cv2
except ImportError as e:
    logger.error("OpenCV import failed - likely not in `owl` virtual environment")
    logger.error(f"Error details: {str(e)}")
    logger.error(f"Python environment: {get_python_env()}")
    raise errors.OpenCVError(str(e)) from None

try:
    import numpy as np
    from utils.input_manager import UteController, AdvancedController, get_rpi_version
    from utils.output_manager import RelayController, HeadlessStatusIndicator, UteStatusIndicator, AdvancedStatusIndicator, GPSStatusLED, GPSLEDState
    from utils.directory_manager import DirectorySetup
    from utils.video_manager import VideoStream, StreamingHandler, ThreadedHTTPServer
    from utils.image_sampler import ImageRecorder
    from utils.algorithms import fft_blur
    from utils.greenonbrown import GreenOnBrown
    from utils.frame_reader import FrameReader
    from utils.config_manager import ConfigValidator
    from utils.log_manager import LogManager, MQTTLogHandler
    from utils.shared_types import Sensitivity
    import utils.error_manager as errors
    from utils.gps_manager import GPSState, parse_sentence
    from version import SystemInfo, VERSION

except ImportError as e:
    missing_module = str(e).split("'")[1]
    logger.error(f"Failed to import required module: {missing_module}")
    logger.error(f"Error details: {str(e)}")
    logger.error(f"Current virtual env: {os.environ.get('VIRTUAL_ENV', 'None')}")
    logger.error(f"Current working directory: {os.getcwd()}")
    raise errors.DependencyError(missing_module, str(e)) from None

logger.info("All required modules imported successfully")


def nothing(x):
    pass


class Owl:
    def __init__(self, show_display=False,
                 input_file_or_directory=None,
                 config_file='config/GENERAL_CONFIG.ini'):
        # set up the logger
        log_dir = Path(os.path.join(os.path.dirname(__file__), 'logs'))
        LogManager.setup(log_dir=log_dir, log_level='INFO')
        self.logger = LogManager.get_logger(__name__)

        self.logger.info("Initializing OWL...")
        self._log_system_info()

        # read the config file
        self._config_path = Path(__file__).parent / config_file
        try:
            self.config = ConfigValidator.load_and_validate_config(self._config_path)
        except errors.OWLConfigError as e:
            self.logger.error(f"Configuration error: {e}", exc_info=True)
            raise

        self.config.read(self._config_path)
        self.config.read(Path(__file__).parent / 'config' / 'CONTROLLER.ini')
        self.RPI_VERSION = get_rpi_version()
        self.logger.info(msg=f'Raspberry Pi version: {self.RPI_VERSION}')

        # is the source a directory/file
        self.input_file_or_directory = input_file_or_directory

        # visualise the detections with video feed
        self.show_display = show_display

        # threshold parameters for different algorithms
        self.exg_min = self.config.getint('GreenOnBrown', 'exg_min')
        self.exg_max = self.config.getint('GreenOnBrown', 'exg_max')
        self.hue_min = self.config.getint('GreenOnBrown', 'hue_min')
        self.hue_max = self.config.getint('GreenOnBrown', 'hue_max')
        self.saturation_min = self.config.getint('GreenOnBrown', 'saturation_min')
        self.saturation_max = self.config.getint('GreenOnBrown', 'saturation_max')
        self.brightness_min = self.config.getint('GreenOnBrown', 'brightness_min')
        self.brightness_max = self.config.getint('GreenOnBrown', 'brightness_max')
        self.min_detection_area = self.config.getint('GreenOnBrown', 'min_detection_area')
        self.invert_hue = self.config.getboolean('GreenOnBrown', 'invert_hue')

        # Sensitivity preset manager
        from utils.sensitivity_manager import SensitivityManager
        self.sensitivity_manager = SensitivityManager(self.config, self._config_path)
        active_preset = self.sensitivity_manager.get_active_preset()
        self.sensitivity_manager.apply_preset(active_preset, self)
        self.logger.info(f"Sensitivity preset '{active_preset}' applied")

        # time spent on each image when looping over a directory
        self.image_loop_time = self.config.getint('Visualisation', 'image_loop_time')

        # setup the track bars if show_display is True
        if self.show_display:
            # create trackbars for the threshold calculation
            self.window_name = "Adjust Detection Thresholds"
            cv2.namedWindow("Adjust Detection Thresholds", cv2.WINDOW_AUTOSIZE)
            cv2.createTrackbar("ExG-Min", self.window_name, self.exg_min, 255, nothing)
            cv2.createTrackbar("ExG-Max", self.window_name, self.exg_max, 255, nothing)
            cv2.createTrackbar("Hue-Min", self.window_name, self.hue_min, 179, nothing)
            cv2.createTrackbar("Hue-Max", self.window_name, self.hue_max, 179, nothing)
            cv2.createTrackbar("Sat-Min", self.window_name, self.saturation_min, 255, nothing)
            cv2.createTrackbar("Sat-Max", self.window_name, self.saturation_max, 255, nothing)
            cv2.createTrackbar("Bright-Min", self.window_name, self.brightness_min, 255, nothing)
            cv2.createTrackbar("Bright-Max", self.window_name, self.brightness_max, 255, nothing)

        self.resolution = (self.config.getint('Camera', 'resolution_width'),
                           self.config.getint('Camera', 'resolution_height'))
        self.exp_compensation = self.config.getint('Camera', 'exp_compensation')
        self.camera_type = self.config.get('Camera', 'camera_type', fallback='auto')

        # Relay Dict maps the reference relay number to a boardpin on the embedded device
        self.relay_dict = {}

        # use the [Relays] section to build the dictionary
        for key, value in self.config['Relays'].items():
            self.relay_dict[int(key)] = int(value)

        # instantiate the relay controller - successful start should beep the buzzer
        try:
            self.relay_controller = RelayController(relay_dict=self.relay_dict)

        except errors.OWLAlreadyRunningError:
            self.logger.critical("OWL initialization failed: GPIO pin conflict. Another OWL instance may be running.",
                                 exc_info=True)
            raise

        ### Data collection only ###
        self.detection_enable = Value('b', self.config.getboolean('DataCollection', 'detection_enable', fallback=False))
        self.image_sample_enable = Value('b', self.config.getboolean('DataCollection', 'image_sample_enable',
                                                                     fallback=False))

        # Local cached versions for performance
        self._detection_enable = self.detection_enable.value
        self._image_sample_enable = self.image_sample_enable.value
        self._STATE_CHECK_INTERVAL = 0.1
        self.stop_state_update = threading.Event()

        ####################### DASHBOARD ############################
        self.dash = None
        self.stream_active = None
        self.latest_stream_frame = None
        mqtt_enable = self.config.getboolean('MQTT', 'enable', fallback=False)

        broker_ip = self.config.get('MQTT', 'broker_ip', fallback='localhost')
        broker_port = self.config.getint('MQTT', 'broker_port', fallback=1883)
        device_id = self.config.get('MQTT', 'device_id', fallback='auto')
        network_mode = self.config.get('Network', 'mode', fallback=None)
        static_ip = self.config.get('Network', 'static_ip', fallback=None)
        client_id = f"client_{device_id}"

        if mqtt_enable:
            try:
                from utils.mqtt_manager import OWLMQTTPublisher

                self.dash = OWLMQTTPublisher(
                    broker_host=broker_ip,
                    broker_port=broker_port,
                    client_id=client_id,
                    device_id=device_id,
                    network_mode=network_mode,
                    static_ip=static_ip)

                self.dash.set_owl_instance(self)

                self.dash.start()

                # Enhanced logging
                mode = 'NETWORKED' if self.dash.networked_mode else 'STANDALONE'
                self.logger.info(f"MQTT enabled - Mode: {mode}")
                self.logger.info(f"MQTT Broker: {broker_ip}:{broker_port}")
                self.logger.info(f"Device ID: {device_id}")
                self.logger.info(f"Client ID: {client_id}")

                # Only attach log handler if broker is already reachable
                if self.dash.connected:
                    LogManager.add_mqtt_handler(
                        mqtt_client=self.dash.client,
                        mqtt_error_topic=self.dash.topics['errors']
                    )

            except Exception as e:
                self.dash = None
                self.logger.warning(f"Failed to initialize MQTT: {e}. Dashboard disabled, OWL continues.")

            try:
                self.stream_lock = threading.Lock()
                self.start_streaming_server()
                self.stream_active = True  # IMPORTANT: Set status to True on success
                self.logger.info("MJPEG video streaming server started successfully")

            except MJPEGStreamError as e:
                self.logger.warning(f"Could not start MJPEG stream, but core functions will continue: {e}")
                self.stream_active = False

            if self.dash:
                self.dash.set_stream_status(self.stream_active)

        # GPS setup
        self.gps_source = self.config.get('GPS', 'source', fallback='none').lower()
        self.gps_data = None
        self._gps_state = None
        self._gps_serial = None
        self._gps_running = False
        self.gps_status_led = None

        if self.gps_source == 'serial':
            self.gps_port = self.config.get('GPS', 'port', fallback='/dev/ttyUSB1')
            self.gps_baudrate = self.config.getint('GPS', 'baudrate', fallback=115200)

            if serial is None:
                self.logger.error("pyserial not installed — serial GPS disabled. Install with: pip install pyserial")
                # Fall back to dashboard (browser geolocation) if available, otherwise disable
                if self.dash:
                    self.gps_source = 'dashboard'
                    self.logger.info("Falling back to dashboard GPS (browser geolocation)")
                else:
                    self.gps_source = 'none'
            else:
                self._gps_state = GPSState()
                self._gps_running = True
                gps_led_raw = self.config.get('Controller', 'gps_led_pin', fallback='38').strip("'\" ").lower()
                if gps_led_raw not in ('', 'none'):
                    self.gps_status_led = GPSStatusLED(pin=f"BOARD{int(gps_led_raw)}")
                self._gps_thread = threading.Thread(target=self._serial_gps_reader, daemon=True)
                self._gps_thread.start()
                self.logger.info(f"Serial GPS reader started on {self.gps_port} @ {self.gps_baudrate}")

        elif self.gps_source != 'none':
            # Non-serial, non-none source (e.g. 'tcp') — fall back to dashboard GPS
            if self.dash:
                self.gps_source = 'dashboard'

        # Create GPS status LED on hardware setups (UTE/Advanced controller) even if GPS
        # source is 'none' — the LED shows whether dashboard browser GPS is active.
        # The LED state is driven by _get_best_gps_data() in the update_state loop.
        if self.gps_status_led is None:
            controller_type_check = self.config.get('Controller', 'controller_type', fallback='none').strip("'\" ").lower()
            if controller_type_check in ('ute', 'advanced'):
                gps_led_raw = self.config.get('Controller', 'gps_led_pin', fallback='38').strip("'\" ").lower()
                if gps_led_raw not in ('', 'none'):
                    self.gps_status_led = GPSStatusLED(pin=f"BOARD{int(gps_led_raw)}")

        # if a controller is connected, sample images must be true to set up directories correctly
        self.controller_type = self.config.get('Controller', 'controller_type').strip("'\" ").lower()
        self.switch_purpose = self.config.get('Controller', 'switch_purpose', fallback='recording').strip("'\" ").lower()

        if self.controller_type not in {'none', 'ute', 'advanced'}:
            self.logger.error(f"Invalid controller type: {self.controller_type}")
            raise errors.ControllerTypeError(self.controller_type, valid_types=list({'none', 'ute', 'advanced'}))

        # Create status indicator EARLY so it can signal boot errors via LED.
        # save_directory is set to None for now; updated after storage setup succeeds.
        # status_led_pin can be 'none' or empty to disable the LED.
        status_led_raw = self.config.get('Controller', 'status_led_pin', fallback='40').strip("'\" ").lower()
        status_led_pin = f"BOARD{int(status_led_raw)}" if status_led_raw not in ('', 'none') else None
        if self.controller_type == 'ute':
            self.status_indicator = UteStatusIndicator(save_directory=None,
                                                       status_led_pin=status_led_pin)
        elif self.controller_type == 'advanced':
            self.status_indicator = AdvancedStatusIndicator(save_directory=None,
                                                            status_led_pin=status_led_pin)
        else:
            self.status_indicator = HeadlessStatusIndicator(save_directory=None, no_save=True)

        if self.controller_type != 'none' and not self.dash:
            self.detection_enable = Value('b', False)
            self.image_sample_enable = Value('b', False)
            self.sensitivity_level = Value('i', Sensitivity.HIGH.value)

        if self.controller_type != 'none' or self.dash:
            # Force infrastructure setup (directories, ImageRecorder) so
            # controller/dashboard can toggle recording when ready.
            # Actual recording state is set after setup — see below.
            self._image_sample_enable = True

        # if controller is 'none' but _image_sample_enable is True, then it will set everything up
        if self._image_sample_enable:
            self.sample_method = self.config.get('DataCollection', 'sample_method')
            self.sample_frequency = self.config.getint('DataCollection', 'sample_frequency')
            self.save_directory = self.config.get('DataCollection', 'save_directory')
            self.camera_name = self.config.get('DataCollection', 'camera_name')

            try:
                self.directory_manager = DirectorySetup(save_directory=self.save_directory)
                self.save_directory, self.save_subdirectory = self.directory_manager.setup_directories()

                self.image_recorder = ImageRecorder(save_directory=self.save_subdirectory, mode=self.sample_method)

                # Update status indicator with the resolved save_directory for storage monitoring
                self.status_indicator.save_directory = self.save_directory

            except (errors.NoWritableUSBError, errors.USBMountError, errors.USBWriteError,
                    errors.StorageSystemError) as e:
                self.logger.critical(str(e))
                # Flash both LEDs in sync to signal boot error — process stays alive
                self.status_indicator.error(6)
                if self.gps_status_led:
                    self.gps_status_led.set_state(GPSLEDState.ERROR)
                self.logger.critical("Both LEDs flashing — storage error. Fix USB drive and restart.")
                # Block here so LEDs keep flashing (systemd will not restart while process is alive)
                try:
                    while True:
                        time.sleep(5)
                except KeyboardInterrupt:
                    self.stop()
                    raise

        ############################

        # initialise controller buttons and async management
        if self.controller_type == 'ute':
            # Status indicator already created above — just set up controller
            self.controller = UteController(
                detection_state=self.detection_enable,
                sample_state=self.image_sample_enable,
                stop_flag=Value('b', False),
                owl_instance=self,
                status_indicator=self.status_indicator,
                switch_purpose=self.config.get('Controller', 'switch_purpose', fallback='recording').strip("'\" ").lower(),
                switch_board_pin=f"BOARD{self.config.getint('Controller', 'switch_pin', fallback=36)}"
            )
            self.controller_process = Process(target=self.controller.run)
            self.controller_process.start()

        elif self.controller_type == 'advanced':
            if not hasattr(self, 'sensitivity_level'):
                self.sensitivity_level = Value('i', Sensitivity.HIGH.value)

            # Status indicator already created above
            self.controller = AdvancedController(
                recording_state=self.image_sample_enable,
                sensitivity_level=self.sensitivity_level,
                detection_mode_state=Value('i', 1),
                stop_flag=Value('b', False),
                owl_instance=self,
                status_indicator=self.status_indicator,
                sensitivity_manager=self.sensitivity_manager,
                recording_bpin=f"BOARD{self.config.getint('Controller', 'recording_pin', fallback=38)}",
                sensitivity_bpin=f"BOARD{self.config.getint('Controller', 'sensitivity_pin', fallback=40)}",
                detection_mode_bpin_up=f"BOARD{self.config.getint('Controller', 'detection_mode_pin_up', fallback=36)}",
                detection_mode_bpin_down=f"BOARD{self.config.getint('Controller', 'detection_mode_pin_down', fallback=35)}"
            )
            self.controller_process = Process(target=self.controller.run)
            self.controller_process.start()

        else:
            self.controller = None
            # Status indicator already created above; start storage monitoring if recording
            if self._image_sample_enable:
                self.status_indicator.start_storage_indicator()

        # Infrastructure is set up. Now set the actual initial recording state.
        # Dashboard-only (no hardware controller): start OFF — user enables via dashboard.
        # Hardware controllers: switch position was read during controller init above.
        if self.dash and self.controller_type == 'none':
            self._image_sample_enable = False
            with self.image_sample_enable.get_lock():
                self.image_sample_enable.value = False
            self.dash.set_image_sample_enable(False)

        if self.dash or self.controller_type != 'none':
            threading.Thread(target=self.update_state, daemon=True).start()
            self.logger.info("State monitoring thread started")

        # Actuation timing — read from [Actuation] (CONTROLLER.ini), fall back to [System]
        if self.config.has_section('Actuation'):
            self.actuation_duration = self.config.getfloat('Actuation', 'actuation_duration',
                                                           fallback=self.config.getfloat('System', 'actuation_duration'))
            self.delay = self.config.getfloat('Actuation', 'delay',
                                              fallback=self.config.getfloat('System', 'delay'))
        else:
            self.actuation_duration = self.config.getfloat('System', 'actuation_duration')
            self.delay = self.config.getfloat('System', 'delay')

        # Loop time tracking (30-frame rolling window)
        self._loop_times = deque(maxlen=30)
        self._avg_loop_time_ms = 0.0

        self.relay_vis = None
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

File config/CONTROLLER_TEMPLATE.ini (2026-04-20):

# =============================================================================
# CONTROLLER.ini — OWL Infrastructure Configuration
# =============================================================================
#
# This file controls how the OWL communicates with dashboards, networks,
# and GPS devices. It is SEPARATE from the detection preset files
# (DAY_SENSITIVITY_1/2/3.ini) which control weed detection parameters.
#
# HOW TO USE:
#   This template is for reference only — it is NOT read by OWL software.
#   The actual CONTROLLER.ini is created automatically when you run:
#
#       sudo bash controller/shared/setup.sh
#
#   (called during owl_setup.sh when you select "yes" to dashboard setup)
#
#   If you need to create or edit CONTROLLER.ini manually, copy this file:
#
#       cp config/CONTROLLER_TEMPLATE.ini config/CONTROLLER.ini
#
#   Then edit the values below to match your setup.
#
# WITHOUT THIS FILE:
#   If CONTROLLER.ini does not exist, OWL runs in basic detection-only mode
#   with no MQTT, no web dashboard, and no remote control. This is the default
#   for a fresh install before setup.sh has been run.
#
# =============================================================================

[MQTT]
# Enable MQTT communication between owl.py and the web dashboard.
# Set to False to disable all dashboard/remote control features.
enable = True

# IP address of the MQTT broker.
#   Standalone mode: use "localhost" (broker runs on the same Pi)
#   Networked mode:  use the IP of the central controller (e.g. 192.168.1.2)
broker_ip = localhost

# MQTT broker port. Default 1883 is standard for unencrypted MQTT.
broker_port = 1883

# Unique identifier for this OWL device on the MQTT network.
# Set to "auto" to use the Pi's hostname (e.g. owl-1), or specify manually.
# Each OWL on a network MUST have a unique device_id.
device_id = auto

[WebDashboard]
# Port for the Flask web dashboard (standalone mode only).
# Nginx proxies HTTPS (port 443) to this internal port.
port = 8000

[Network]
# Operation mode — determines MQTT topic structure and network behaviour.
#
#   standalone — OWL creates its own WiFi hotspot and runs a local MQTT broker.
#                The standalone dashboard (controller/standalone/) connects locally.
#                MQTT topics: owl/state, owl/commands (flat, no device ID)
#
#   networked  — OWL connects to an existing WiFi network and publishes to a
#                remote MQTT broker on the central controller.
#                The networked dashboard (controller/networked/) discovers OWLs
#                automatically via device-specific MQTT topics.
#                MQTT topics: owl/{device_id}/state, owl/{device_id}/commands
#
mode = standalone

# Static IP address assigned to this OWL.
#   Standalone mode: always 10.42.0.1 (hotspot gateway)
#   Networked mode:  the static IP configured during setup (e.g. 192.168.1.11)
static_ip = localhost

# IP address of the central controller (networked mode only).
# In standalone mode this is ignored — set to "localhost" for clarity.
controller_ip = localhost

[GPS]
# ===========================================================================
#  GPS Configuration
#  This section controls the GPS/NMEA input used by owl.py (on-Pi detection)
#  and the networked controller dashboard. A valid GPS fix enables:
#    - Speed-adaptive solenoid actuation timing
#    - Track recording as GeoJSON breadcrumbs for the map display
#    - Session stats: distance travelled, time active, hectares sprayed
#
#  In networked mode, individual OWL units automatically defer to the
#  central controller for GPS — only the controller needs real GPS hardware.
# ===========================================================================

# --- source ----------------------------------------------------------------
# Where the controller reads NMEA sentences from. Pick ONE:
#
#   none     GPS disabled entirely. No map, no speed-adaptive actuation,
#            no track recording. (Default — safe for bench testing.)
#
#   serial   Read NMEA from a USB or UART serial device plugged directly
#            into this Pi. Use this for Ublox USB dongles, Adafruit GPS
#            HATs, or any GPS module that exposes a /dev/tty* device.
#            Requires pyserial (already in the venv — no extra install).
#
#   tcp      Listen on a TCP port for NMEA sentences pushed from a router
#            (e.g. Teltonika RUTX14). The router handles the GPS hardware
#            and streams NMEA over the network to this controller.
#
#   gpsd     Read from the Linux gpsd daemon running on localhost:2947.
#            Useful when multiple apps on the same Pi need GPS, or when
#            you want gpsd to handle reconnects, device probing, and
#            SBAS corrections. Requires `apt install gpsd gpsd-clients`
#            (the in-cab setup script installs it for you if selected).
source = none
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

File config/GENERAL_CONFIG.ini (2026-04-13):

[System]
algorithm = exhsv
input_file_or_directory = 
relay_num = 4
actuation_duration = 0.15
delay = 0
actuation_zone = 100

[Controller]
controller_type = none

# Shared LED pins (BOARD numbering, set to 'none' to disable)
status_led_pin = 40
gps_led_pin = 38

# Ute controller (single switch — controls recording OR detection)
switch_purpose = recording
switch_pin = 36

# Advanced controller (3-position detection mode + recording + sensitivity switches)
detection_mode_pin_up = 36
detection_mode_pin_down = 35
recording_pin = 33
sensitivity_pin = 32
# Previous defaults (pre-2026-04): recording_pin = 38, sensitivity_pin = 40
# Changed because 38/40 conflicted with gps_led_pin/status_led_pin

[Visualisation]
image_loop_time = 5

[Camera]
resolution_width = 1456
resolution_height = 1088
exp_compensation = -2
crop_factor_horizontal = 0.02
crop_factor_vertical = 0.02
camera_type = auto

[GreenOnGreen]
model_path = models
confidence = 0.5
detect_classes = 
actuation_mode = centre
min_detection_pixels = 50
inference_resolution = 320
crop_buffer_px = 20

[GreenOnBrown]
exg_min = 25
exg_max = 200
hue_min = 39
hue_max = 83
saturation_min = 50
saturation_max = 220
brightness_min = 60
brightness_max = 190
min_detection_area = 10
invert_hue = False

[DataCollection]
image_sample_enable = False
detection_enable = True
sample_method = whole
sample_frequency = 30
save_directory = owl_data
log_fps = False
camera_name = cam1

[Relays]
0 = 13
1 = 15
2 = 16
3 = 18

[Tracking]
tracking_enabled = False
track_high_thresh = 0.1
track_low_thresh = 0.05
new_track_thresh = 0.05
track_buffer = 100
match_thresh = 0.2
track_class_window = 5
track_crop_persist = 3
detection_persist_frames = 10

[Sensitivity]
active = medium

[Sensitivity_Low]
exg_min = 25
exg_max = 200
hue_min = 41
hue_max = 80
saturation_min = 52
saturation_max = 218
brightness_min = 62
brightness_max = 188
min_detection_area = 20

[Sensitivity_Medium]
exg_min = 25
exg_max = 200
hue_min = 39
hue_max = 83
saturation_min = 50
saturation_max = 220
brightness_min = 60
brightness_max = 190
min_detection_area = 10

[Sensitivity_High]
exg_min = 22
exg_max = 210
hue_min = 35
hue_max = 85
saturation_min = 40
saturation_max = 225
brightness_min = 50
brightness_max = 200
min_detection_area = 5

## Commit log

2021-08-23 Initial commit
    The first public commit of the OpenWeedLocator repository!
    [HQ camera mount.stl, PiCamera v2 mount.stl, Raspberry Pi mount.stl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]
2021-08-31 Updated HQ camera mount
    [HQ camera mount.stl]
2021-09-06 Improves LED description, UART enabling
2021-09-07 Updated enclosure cover
    [Tall enclosure cover.stl]
2022-01-10 Fixes log file bug
    [button_inputs.py]
2022-03-04 Updated camera mount
    [Camera mount.stl]
2022-03-04 New enclosure files
    New files for redesigned enclosure. Updated camera mounting and shorter footprint for better compatibility with more 3D printers.
    [Enclosure - cable gland.stl, Enclosure - cover.stl, Enclosure - single connector.stl]
2022-03-04 Update README.md
    Updated hardware assembly instructions for improved camera mount.
    Updated Open CV install instructions after testing.
2022-05-02 Update 3 enclosure designs
    new enclosures include lens cover mount
    [Enclosure - cable gland.stl, Enclosure - single connector.stl]
2022-05-02 add Buzzer, OutputDevice to relay_control
2022-05-02 add argparse, replace headless with show-display
    [greenonbrown.py]
2022-05-12 add sensor_mode args
2022-05-29 add nozzleNum to options listed
2022-05-29 update analysis for single frames
2022-08-17 fix AttributeError
    temporary fix for #49
    [greenonbrown.py]
2023-02-15 add in visualisation of nozzles
2023-03-17 change gog imports to avoid import errors
    [owl.py]
2023-03-17 fix centre coordinate calculation
    [greenongreen.py]
2023-07-30 fix errors from Raspberry Pi
    [owl.py]
2023-08-31 Update frame_reader.py
    clean code
2023-12-11 add gog error checking
    [greenongreen.py, owl.py]
2023-12-29 improve gog error checking
    [greenongreen.py, owl.py]
2023-12-29 add in nozzlevis
2024-02-05 Added summary for button_inputs.py
2024-02-06 Added summary for relay_control.py
2024-04-07 implement custom camera streaming
2024-04-09 fix picamera2 support bugs
    [owl.py]
2024-04-11 add camera src for picamera2stream
2024-04-19 update README.md, fix cli flags
    [owl.py]
2024-04-19 fix bugs in README.md, FPS logging
    [owl.py]
2024-04-30 fix led bug
2024-05-08 add 3D models, installation guide, update image collection
    [Backplate - Gland.stl, Backplate - Receptacle Only.stl, Backplate - Receptacle and Ethernet.stl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]
2024-05-09 add relay HAT installation to readme.md
2024-05-17 add FUNDING.yml, rotate frame
2024-05-18 add wait for frame, remove .copy()
2024-07-02 add updated tray and lens holder
    [Tray - base.stl, Tray - lens holder.stl]
2024-07-03 add fixed main body.stl
    [Main Body.stl]
2024-07-03 add updated backplates
    includes additional blank backplate
    [Backplate - blank.stl, Backplate - gland.stl, Backplate - receptacle and ethernet.stl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]
2024-08-08 add notifications, fix USB bug
    [directory_manager.py, input_manager.py, output_manager.py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]
2024-08-14 remove rpi-update, fix bugs
    [greenonbrown.py, owl.py, video_manager.py]
2024-10-15 Revert "handle unmounted USB drives"
    This reverts commit ac89e00ff31b7ff4607ff6f2418218bc66730e2e.
    [directory_manager.py]
2024-10-16 add better error management
    [directory_manager.py, error_manager.py, output_manager.py]
2024-11-04 add controller instructions
    [Advanced Controller - Top - Single OWL.stl, Advanced OWL Controller - Base - Single OWL.stl, Advanced OWL Controller - Bottom - Double OWL.stl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]
2024-11-05 update controller instructions
    [Advanced Controller - Base - 4 OWL.stl, Advanced Controller - Base - Double OWL.stl, Advanced Controller - Base - Single OWL.stl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]
2024-11-06 update logging and error management
    [config_manager.py, directory_manager.py, error_manager.py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]
2024-11-29 fix input file bug
    [error_manager.py, owl.py]
2024-11-29 fix ImageRecorder logging bug
    [image_sampler.py]
2025-02-14 Add fixed Frontplate.stl
    [Frontplate.stl]
2025-02-14 Add modified backplate
    [Rear cover - 2 x Amphenol receptacle.stl]
2025-02-14 Rename Rear cover - 2 x Amphenol receptacle.stl to Backplate - 2 x Amphenol receptacle.stl
    [Backplate - 2 x Amphenol receptacle.stl]
2025-07-09 fix download frame
2025-07-09 add device number check
2025-07-09 fix authentication and frame access issues
2025-07-09 fix recording issues, directory setup
    [owl.py]
2025-07-09 fix connection to owl_dash.py, improve UX
    [owl.py]
2025-07-10 fix shared state logic
    [image_sampler.py, input_manager.py, owl.py]
2025-07-10 update mqtt frame handling
2025-07-10 add frame throttling, update mqtt setup
2025-07-11 update setup script, change frame streaming
2025-07-24 fix pin assignment
2025-07-24 fix image out logic, weed detect indicator
    [owl.py]
2025-07-24 remove frame overlays
2025-08-04 pin package versions
2025-08-04 fix ThreadedHTTPServer indentation issue
    [video_manager.py]
2025-08-04 fix systemd MQTT workers issue
    [video_manager.py]
2025-08-04 update errors, fix stream overlay
    [error_manager.py, mqtt_manager.py, owl.py]
2025-08-04 add fan status
2025-08-04 add fan setup
2025-08-04 fix fan html
2025-08-04 update fan state
2025-08-05 fix rpi version error
    [error_manager.py, input_manager.py]
2025-08-11 move control buttons to dash tab
2025-08-14 log errors to dash
    [log_manager.py, mqtt_manager.py, owl.py]
2025-08-14 add power button
2025-08-14 fix systemctl path, remove pinctrl path error
    [owl.py]
2025-08-15 update sensitivity logic, dashboard, fan, appearance
2025-08-28 update jpeg save, config logic, camera error
    [image_sampler.py, video_manager.py]
2025-11-02 fix video, stats, display
    [mqtt_manager.py, owl.py]
2025-11-02 update device id
2025-12-03 add frame size error
    [owl.py]
2025-12-03 add usb camera support
2025-12-03 add usb camera test
2025-12-03 update camera index selection
2025-12-03 fix camera selection, update camera config
    [owl.py, video_manager.py]
2025-12-28 fix mqtt disabled sensitivity bug, sensitivity level spam
    [mqtt_manager.py, owl.py]
2025-12-29 fix dir path, save button
2026-02-08 significant controller restructuring, add shared components, new UI
    [active_config.txt]
2026-02-08 fix migration issues, update README.md
    [config_manager.py, owl.py, test_config_files.py]
2026-02-10 improve config arrangements, update testing
    [active_config.txt]
2026-02-10 fix gps, add tester
    [gps_manager.py]
2026-02-11 fix dashboards UI, bugs
    [active_config.txt]
2026-02-11 fix errors bricking dash, improve config editor tab
    [active_config.txt]
2026-02-12 add Threaded hybrid mode for efficiency, fix config issues on standalone.py
    [greenongreen.py]
2026-02-12 fix relay allocation logic
    [greenonbrown.py, greenongreen.py, owl.py]
2026-02-12 fix layout, add actuation length
    [config_manager.py, owl.py]
2026-02-13 add model upload page, fix UI, add 'All Nozzles' button
    [mqtt_manager.py]
2026-02-13 add demo page, fix image polling issues
    [input_manager.py, mqtt_manager.py]
2026-02-13 fix sha errors on zipped uploads
    [mqtt_manager.py]
2026-02-13 fix task detection, add NCNN
    [greenongreen.py]
2026-02-13 fix relay number conflict with buzzer
    [config_manager.py, output_manager.py]
2026-03-11 add config keypad, reduce to GENERAL_CONFIG.ini, fix owl boot setup.sh
    [active_config.txt]
2026-03-11 add power and screen fix buttons
    [mqtt_manager.py, owl.py, test_config_files.py]
2026-03-30 add agent runtime
    [active_config.txt]
2026-03-30 update GPS logic
    [active_config.txt]
2026-04-04 fix downloads page, incorporate USB camera changes from main
    [GENERAL_CONFIG.ini, config_manager.py, directory_manager.py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]
2026-04-13 fix display bug, improve GENERAL_CONFIG.ini clarity, update docs
    [GENERAL_CONFIG.ini, config_manager.py, output_manager.py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]
2026-04-13 update switch
2026-04-21 add metadata recording, fix start sequence
    [test_config_files.py]
2026-10-09 add RAM Mount sleeve
    A RAM mount sleeve for the Compact OWL for easier mounting.

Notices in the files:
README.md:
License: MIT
